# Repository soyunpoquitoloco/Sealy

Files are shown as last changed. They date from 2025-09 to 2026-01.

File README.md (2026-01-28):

# Sealy 🦭  
**Playful robotic companion for everyday productivity (posture • fatigue • phone distraction)**

Sealy is a small, seal-like desktop companion that supports focus through **low-demand, nonverbal mirroring**. Instead of notifications, scores, or “warnings,” Sealy uses **slow, peripheral, socially legible motions**:
- **Posture drift →** Sealy subtly *slumps* to mirror you  
- **Fatigue cues →** Sealy *gradually closes its eyelids*  
- **Phone distraction →** Sealy *turns away* from its “fishing hole” by rotating its base

Capture d’écran 2026-01-28 à 01 43 39

This repo contains the **software**, **hardware notes**, and **fabrication assets** used to build and run Sealy.  
(Technical and study protocol details are documented in the accompanying paper.) :contentReference[oaicite:0]{index=0}

---

## Contents
- [Project at a glance](#project-at-a-glance)
- [Prototype iterations](#prototype-iterations)
- [Repository layout](#repository-layout)
- [System overview](#system-overview)
- [Bill of materials](#bill-of-materials)
- [Fabrication & assembly](#fabrication--assembly)
- [Software setup](#software-setup)
- [How to use](#how-to-use)
- [Preliminary lab study & evaluation plan](#preliminary-lab-study--evaluation-plan)
- [Media](#media)
- [Citation](#citation)

---

## Project at a glance
**Design goal:** Reduce brief self-regulation lapses (posture drift, fatigue, phone checks) with **ambient co-regulation** cues that feel **supportive, not supervisory**. :contentReference[oaicite:1]{index=1}

**Key design constraints:**
- perceivable in peripheral vision  
- no speech, alerts, or explicit “correction”  
- slow transitions, small amplitudes  
- avoid “being watched” impressions via on-device inference and minimal logging :contentReference[oaicite:2]{index=2}

---

## Prototype iterations

There are **four physical prototypes**. 

Capture d’écran 2026-01-28 à 01 42 11

### Prototype 1 — Origami scale mock
**What it was:** Paper origami seal.

**Why:**  
- validate **desk footprint**, approximate height, and “presence” in peripheral vision  
- test early **role framing** (“pet” vs “monitor”) without committing to materials or mechanics  
- quickly iterate silhouette (roundness, head size, flipper placement) for “baby-schema” readability :contentReference[oaicite:3]{index=3}

**What we learned → what changed next:**  
Origami is great for proportions but can’t validate **mount points**, servo routing, or deformation. Next step required a rigid, printable geometry to start integrating mechanisms.

---

### Prototype 2 — 3D printed PLA body
**What it was:** Full PLA print of Sealy.

**Why:**  
- confirm **3D model correctness** (surface continuity, eye/face legibility, printability)  
- test **mechanical integration**: internal clearances, routing for eyelids/posture line, base interface  
- verify “desk object” presence and camera placement constraints

**What we learned → what changed next:**  
PLA validates geometry, but the interaction goal includes a **soft companion feel** (tactility + deformation). Rigid plastic reads more like a gadget/toy shell and limits lifelike slumping. Next step: silicone casting.

---

### Prototype 3 — Silicone cast (full silicone, rigid feel)
**What it was:** Silicone part cast in a 3D printed mold, but **the body is fully silicone (solid)** → results in *low flexibility* for expressive deformation.

**Why:**  
- explore **tactile affordances** (softness, warmth, “pet-like” handling)  
- attempt deformation-driven motions (slump/breathing) via material compliance rather than only joints

**What we learned → what changed next:**  
A **fully-solid silicone** body tends to be:
- **too stiff / too massive** to deform visibly with small servos
- harder to create predictable motion (deformation becomes “mushy” or barely noticeable)
- difficult for cable/servo integration (channels, anchors, eyelid linkage)

So the next iteration needed **softness at the surface** *without* losing a controllable internal structure.

---

### Prototype 4 — Silicone “skin” (Rebound 25) over PLA core (flexible outer layer)
**What it was:** A PLA printed model used to create a silicone skin using **Rebound 25**, keeping **only the external silicone layer** (more flexible), with an internal rigid structure for mounting.

**Why this solved Prototype 3’s limits:**
- **Soft-touch exterior** preserves pet-like tactility and “cute” embodiment
- **Rigid inner core** provides:
  - stable servo mounts and anchors (posture line, eyelid linkage)
  - consistent kinematics (repeatable slump angle, eyelid closure range)
- **Lower actuation load**: servos deform a thin skin far more effectively than a solid silicone block

This aligns with Sealy’s technical intent: expressive, low-amplitude motion that remains readable and calm. :contentReference[oaicite:4]{index=4}

---

## Repository layout

```
Companion/
├── README.md                          # This file
├── yolov8n.pt                         # YOLOv8n model weights
│
├── Programme PC/                      # PC-side programs
│   ├── detect_phone.py                # Phone detection module
│   ├── Emotions.py                    # Emotion detection (legacy)
│   ├── Posture_old.py                 # Old posture detection
│   ├── yolov8n.pt                     # Model weights (copy)
│   │
│   ├── Digital/                       # Digital prototype
│   │   ├── Animation.py               # Animation logic
│   │   ├── Detection.py               # Detection pipeline
│   │   └── main.py                    # Entry point
│   │
│   ├── Programme_general/             # Main integrated system
│   │   ├── main.py                    # Main detection loop (posture + phone)
│   │   ├── posture.py                 # Posture calibration & detection
│   │   ├── websocket_client.py        # WebSocket communication to ESP32
│   │   └── yolov8n.pt                 # Model weights
│   │
│   └── tiredness_detection/           # Fatigue detection system
│       ├── main.py                    # Entry point
│       ├── config.py                  # Configuration parameters
│       ├── fatigue_detector.py        # Core fatigue detection
│       ├── metrics.py                 # EAR, MAR metrics
│       ├── requirements.txt           # Python dependencies
│       └── README.md                  # Module documentation
```

---

## System overview

### Sensing (PC / webcam)
Sealy uses on-device computer vision to estimate:
- **Posture** via **MediaPipe Pose** (baseline calibration, then compare shoulder/spine deviation)
- **Fatigue** via **MediaPipe Face Mesh** (EAR, MAR, PERCLOS-style eye closure)
- **Phone use** via pose + **YOLOv8n** object detection :contentReference[oaicite:6]{index=6}

### State → behavior mapping (robot)
- **Posture drift →** servo-driven “slump” (mirrors direction/weight)
  
Capture d’écran 2026-01-28 à 01 46 07

- **Fatigue →** eyelids gradually close; tempo reduces
  
- **Phone distraction →** base rotates away from the fishing hole :contentReference[oaicite:7]{index=7}
  
Capture d’écran 2026-01-28 à 01 45 13

### Comms
PC runs a processing loop and transmits state to the device via a **WebSocket**-style connection for synchronized responses. :contentReference[oaicite:8]{index=8}

---

## Bill of materials

### Electronics
- Webcam (PC-facing; can be laptop webcam)
- **1× stepper motor** + driver (for rotating base)
- **2× servo motors**
  - posture/breathing (pull line)
  - eyelids (wire linkage)
- Controller: **ESP32 Devkit** 
- Power supply 5V
- Wires, connectors

Capture d’écran 2026-01-28 à 01 49 39

### Mechanical
- Rotating platform + gear assembly (for ice-floe metaphor)
- Fishing-hole top reference (visual orientation cue)
- Transparent fishing line (posture actuation, eyelids)
  
Capture d’écran 2026-01-28 à 01 50 16

### Fabrication
- PLA filament (body core, base components, molds as needed)
- Silicone: **Rebound 25** (skin)
- Mold release spray + mixing supplies (cups, stir sticks, gloves)

---

## Fabrication & assembly

### A) Build the body (Prototype 4 recommended)
1. **3D print** the Sealy body core in PLA and the other components.
2. Prepare the **mold workflow** for a thin silicone skin:
   - use the PLA model as the master
   - apply mold release
3. Mix and brush/apply **Rebound 25** in layers to achieve a uniform skin thickness.
4. Demold the skin.

Capture d’écran 2026-01-28 à 01 54 27

**Why this works:** thin silicone skin gives visible deformation under low torque, while the PLA core allowed to keep motion repeatable.

### B) Assemble the base (rotation)
1. Mount the stepper motor, and platform.
2. Ensure the base can rotate smoothly through the intended angle range (e.g., ~30° for “turn away”). :contentReference[oaicite:10]{index=10}
3. Align Sealy with the platform to make it face the fishing hole.

### C) Add actuators
- **Posture servo:** attach fishing line to a secure anchor on Sealy’s back; route line to servo horn so it can “pull” a controlled slump.
- **Eyelid servo:** connect eyelids via thin wires so the servo can close them gradually (aim ~50% closure for readability). :contentReference[oaicite:11]{index=11}

### D) Wire + power
- Keep stepper power isolated/adequate; servos can brown-out controllers if underpowered.
- Strain-relief all moving wires (rotation + servo motion).

---

## Software setup

### 1) PC-side (vision + state server)
**Expected dependencies:**
- Python 3.9+
- `opencv-python`
- `mediapipe`
- `ultralytics` (YOLOv8)
- `numpy`
- `websockets` (or equivalent)

**Installation:**
```bash
pip install opencv-python mediapipe ultralytics numpy websockets
```

**Directory options:**

- **`Programme_general/`** (recommended): integrated posture + phone detection with WebSocket communication
  ```bash
  cd "Programme PC/Programme_general"
  python main.py
  ```

- **`tiredness_detection/`**: standalone fatigue detection system
  ```bash
  cd "Programme PC/tiredness_detection"
  pip install -r requirements.txt
  python main.py
  ```
  
  Optional arguments:
  - `--camera-index N` — select camera device (default: 0)
  - `--no-calibration` — skip calibration, use default thresholds
  - `--ear-threshold 0.20` — customize eye aspect ratio threshold
  - `--log-level DEBUG` — set logging verbosity

**Configuration:**
- On first run, the system will **calibrate** your neutral posture (stay upright for ~5 seconds)
- Adjust detection thresholds in `config.py` (fatigue module) or directly in `main.py` scripts
- Ensure YOLOv8n weights (`yolov8n.pt`) are present in the working directory

---

### 2) Device-side (ESP32)

**Expected dependencies:**
- Arduino IDE or PlatformIO for ESP32 development
- ESP32 board support package
- Required libraries:
  - `ESP32Servo` (for servo control)
  - `AccelStepper` or `Stepper` (for stepper motor)
  - `WebSocketsServer` or `AsyncWebSocket` (for WebSocket communication)

**Setup:**
1. Flash firmware to ESP32:
   - Open the ESP32 firmware project in Arduino IDE or PlatformIO
   - Configure WiFi credentials and WebSocket port
   - Upload to ESP32 board

2. Configure PC connection:
   - Update WebSocket endpoint in `Programme_general/websocket_client.py` with your ESP32's IP address
   - Ensure both PC and ESP32 are on the same network

**Hardware wiring:**
- Connect servos to ESP32 GPIO pins (servo1 for slumping : 27, servo2 for eyelids : )
- Connect stepper motor driver to appropriate pins (Pin1 : 13, Pin2 : 26, Pin3 : 25, Pin4 : 33) 
- Use external power supply for motors 5V
---

## How to use

### First-time setup
1. **Build the physical prototype** (see [Fabrication & assembly](#fabrication--assembly))
2. **Install software** on both PC and ESP32 (see [Software setup](#software-setup))
3. **Connect hardware**: plug in webcam, power on Sealy, establish PC ↔ ESP32 communication
4. **Calibrate**: run the PC program and hold good posture during calibration countdown

### Daily use workflow
1. **Start the ESP32** (ensure it's powered on and connected to WiFi)
2. **Start PC detection**:
   ```bash
   cd "Programme PC/Programme_general"
   python main.py
   ```
3. **Position yourself** in front of the webcam, with Sealy visible in your peripheral vision
4. **Work naturally** — Sealy will respond to:
   - **Posture drift**: if you slump or lean, Sealy mirrors the motion

Capture d’écran 2026-01-28 à 02 03 16

   - **Fatigue signs**: if your eyes close repeatedly, Sealy's eyelids droop

Capture d’écran 2026-01-28 à 02 03 48

   - **Phone checks**: if you pick up your phone, Sealy rotates away from the fishing hole

Capture d’écran 2026-01-28 à 02 04 12

### Interpreting Sealy's cues
- **Slump motion** → gentle reminder to adjust posture (not a "correction," just mirroring)
- **Eyelid closure** → fatigue detected; consider a break or eye rest
- **Base rotation** → phone distraction noticed; Sealy "looks away" to create ambient awareness

### Stopping / pausing
- Press `q` or `Ctrl+C` in the terminal to stop detection
- Device motors return to neutral positions
- No data is logged by default (privacy by design)

---

## Preliminary lab study & evaluation plan

### Study goals
Evaluate whether **nonverbal ambient cues** from Sealy can:
1. Reduce frequency/duration of posture lapses, fatigue incidents, and phone checks
2. Feel supportive rather than supervisory (subjective perception)
3. Maintain effectiveness over multi-day usage (habituation assessment)

### Study design (future work)
- **Participants**: 4 workers (students/office workers)
- **Protocol**: 
  - Baseline session (no Sealy): 15-20 min focused task
  - Sealy session: 15-20 min focused task with Sealy active
  - Counterbalanced order (half start with Sealy, half without)
- **Measures**:
  - **Quantitative**: posture deviation frequency, phone pickup count, eye closure duration (via logs)
  - **Qualitative**: post-session interview (NASA-TLX workload, perceived support vs. surveillance)

### Next steps
- Test on 4 participant
- Long-term deployment (1 week) to assess habituation
- Compare Sealy to explicit notifications (e.g., popup alerts) for perceived intrusiveness

---

## Media

### Photos

Capture d’écran 2026-01-28 à 01 56 21

Capture d’écran 2026-01-28 à 01 56 45

### Demo videos

https://github.com/user-attachments/assets/3ee4d5ab-db28-43dc-951a-25afe59001c0

### Design process

Capture_d_écran_2026-01-22_à_23 58 56-removebg-preview

Capture_d_écran_2026-01-22_à_23 59 40-removebg-preview

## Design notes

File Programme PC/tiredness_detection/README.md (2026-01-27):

# Fatigue Detection System

Système de détection de fatigue en temps réel utilisant la webcam. Détecte les signes de fatigue comme les yeux fermés, les bâillements et les clignements prolongés.

## Fonctionnalités

- **Détection en temps réel** : Analyse vidéo à 15-30 FPS sur CPU
- **Détection des yeux fermés** : EAR (Eye Aspect Ratio) + PERCLOS
- **Détection des bâillements** : MAR (Mouth Aspect Ratio)
- **Clignements longs** : Détection des micro-siestes
- **Score de fatigue** : Calcul pondéré avec lissage
- **Alertes intelligentes** : Hystérésis + cooldown
- **Calibration automatique** : Adaptation à l'utilisateur
- **Privacy-first** : Tout en local, pas d'enregistrement

## Prérequis

- Python 3.10 ou supérieur
- Webcam fonctionnelle
- macOS, Linux ou Windows

## Installation

### 1. Cloner ou créer le projet

```bash
cd /Users/emilie/tiredness_detection
```

### 2. Créer un environnement virtuel (recommandé)

```bash
python3 -m venv venv
source venv/bin/activate  # Sur macOS/Linux
# ou
venv\Scripts\activate  # Sur Windows
```

### 3. Installer les dépendances

```bash
pip install -r requirements.txt
```

## Utilisation

### Lancement basique

```bash
python main.py
```

### Options disponibles

```bash
# Utiliser une autre caméra
python main.py --camera-index 1

# Désactiver la calibration
python main.py --no-calibration

# Ajuster les seuils
python main.py --ear-threshold 0.18 --mar-threshold 0.65

# Mode debug
python main.py --log-level DEBUG
```

### Commandes pendant l'exécution

- **`q`** : Quitter l'application
- **`r`** : Réinitialiser l'état de fatigue

## Métriques affichées

| Métrique | Description | Valeurs normales |
|---|---|---|
| **EAR** | Eye Aspect Ratio | 0.25-0.35 (ouvert), <0.20 (fermé) |
| **MAR** | Mouth Aspect Ratio | <0.5 (fermé), >0.6 (bâillement) |
| **PERCLOS** | % temps yeux fermés | <15% (OK), >15% (fatigue) |
| **Yawns/min** | Bâillements par minute | <3 (OK), >3 (fatigue) |
| **Score** | Score de fatigue global | <0.5 (OK), >0.5 (fatigue) |

## Configuration

Tous les paramètres sont ajustables dans `config.py` :

### Seuils principaux

```python
# Yeux
EAR_THRESHOLD = 0.21              # Seuil EAR pour yeux fermés
EYE_CLOSED_MIN_FRAMES = 2         # Frames min pour considérer fermé
PERCLOS_THRESHOLD = 0.15          # 15% du temps

# Bâillements
MAR_THRESHOLD = 0.6               # Seuil MAR pour bâillement
YAWN_MIN_FRAMES = 10              # Frames min pour bâillement

# Score de fatigue
FATIGUE_SCORE_THRESHOLD = 0.5     # Seuil d'alerte
FATIGUE_TRIGGER_SECONDS = 3.0     # Durée avant alerte
FATIGUE_COOLDOWN_SECONDS = 10.0   # Cooldown entre alertes
```

### Poids du score de fatigue

```python
WEIGHT_PERCLOS = 0.4       # 40% du score
WEIGHT_YAWNS = 0.3         # 30% du score
WEIGHT_LONG_BLINKS = 0.3   # 30% du score
```

### Calibration

```python
CALIBRATION_ENABLED = True
CALIBRATION_DURATION_SECONDS = 5.0
CLOSED_RATIO = 0.70  # Seuil = 70% de l'EAR moyen ouvert
```

## Architecture

```
tiredness_detection/
├── main.py                 # Point d'entrée, boucle principale
├── fatigue_detector.py     # Classe FatigueDetector
├── metrics.py              # Calculs EAR, MAR, PERCLOS
├── config.py               # Configuration et seuils
├── requirements.txt        # Dépendances
└── README.md              # Documentation
```

### Flux de traitement

```
Webcam → MediaPipe FaceMesh → Landmarks
                                  ↓
                    ┌─────────────┴─────────────┐
                    ↓                           ↓
                 Yeux (EAR)                 Bouche (MAR)
                    ↓                           ↓
              ┌─────┴────┐                 Bâillements
              ↓          ↓                      ↓
         PERCLOS    Long Blinks           Yawns/min
              ↓          ↓                      ↓
              └──────────┴──────────────────────┘
                             ↓
                      Fatigue Score
                             ↓
                      ┌──────┴──────┐
                      ↓             ↓
                  OK/WARNING    FATIGUE ALERT
```

## Ajustements et optimisation

### Si trop d'alertes

1. Augmenter `FATIGUE_SCORE_THRESHOLD` (ex: 0.6 ou 0.7)
2. Augmenter `FATIGUE_TRIGGER_SECONDS` (ex: 5.0)
3. Réduire les poids `WEIGHT_*`
4. Augmenter `EAR_THRESHOLD` (ex: 0.19)

### Si pas assez d'alertes

1. Diminuer `FATIGUE_SCORE_THRESHOLD` (ex: 0.4)
2. Diminuer `EAR_THRESHOLD` (ex: 0.23)
3. Diminuer `MAR_THRESHOLD` (ex: 0.55)
4. Augmenter les poids `WEIGHT_*`

### Optimisation performance

- Réduire `FRAME_WIDTH` et `FRAME_HEIGHT` dans config.py
- Désactiver `DRAW_LANDMARKS` si non nécessaire
- Réduire `PERCLOS_WINDOW_SECONDS` pour moins d'historique

## Résolution de problèmes

### Caméra ne s'ouvre pas

```bash
# Tester les indices disponibles
python -c "import cv2; print([i for i in range(5) if cv2.VideoCapture(i).isOpened()])"

# Utiliser l'indice trouvé
python main.py --camera-index <indice>
```

### FPS faible (<15)

- Fermer les autres applications utilisant la caméra
- Réduire la résolution dans config.py
- Vérifier les processus CPU

### Pas de détection de visage

- Assurez-vous d'être bien éclairé
- Positionnez-vous face à la caméra
- Ajustez `MIN_DETECTION_CONFIDENCE` dans config.py

### Alertes erratiques

- Lancez avec calibration activée
- Ajustez `SCORE_SMOOTHING_ALPHA` (0.2-0.4)
- Augmentez `FATIGUE_TRIGGER_SECONDS`

## Landmarks MediaPipe

Le système utilise MediaPipe FaceMesh (468 landmarks) :

- **Yeux gauche** : indices 33, 160, 158, 133, 153, 144, etc.
- **Yeux droit** : indices 362, 385, 387, 263, 373, 380, etc.
- **Bouche** : indices 61, 291, 13, 14, 12, 15, 11, 16, etc.

Voir [MediaPipe Face Mesh](https://github.com/google/mediapipe/blob/master/docs/solutions/face_mesh.md) pour les détails.

## Améliorations futures (TODO)

- [ ] **Head pose estimation** : Détection de la tête qui tombe
- [ ] **Export des données** : Logging des métriques (CSV)
- [ ] **Alertes sonores** : Notification audio configurable
- [ ] **Dashboard** : Graphiques temps réel
- [ ] **Multi-visages** : Support de plusieurs personnes
- [ ] **GPU acceleration** : Support CUDA/Metal
- [ ] **Configuration UI** : Interface pour ajuster les seuils

## Licence

Projet éducatif - Libre d'utilisation et de modification.

## Crédits

- **MediaPipe** : Google (détection de visage et landmarks)
- **OpenCV** : Traitement d'image et vidéo
- **EAR/MAR** : Métriques basées sur la recherche académique

## Support

Pour toute question ou problème, ouvrez une issue ou consultez les logs avec `--log-level DEBUG`.

---

**Note** : Ce système est conçu pour la détection de fatigue en temps réel mais ne remplace pas une évaluation médicale professionnelle. Utilisez-le de manière responsable.

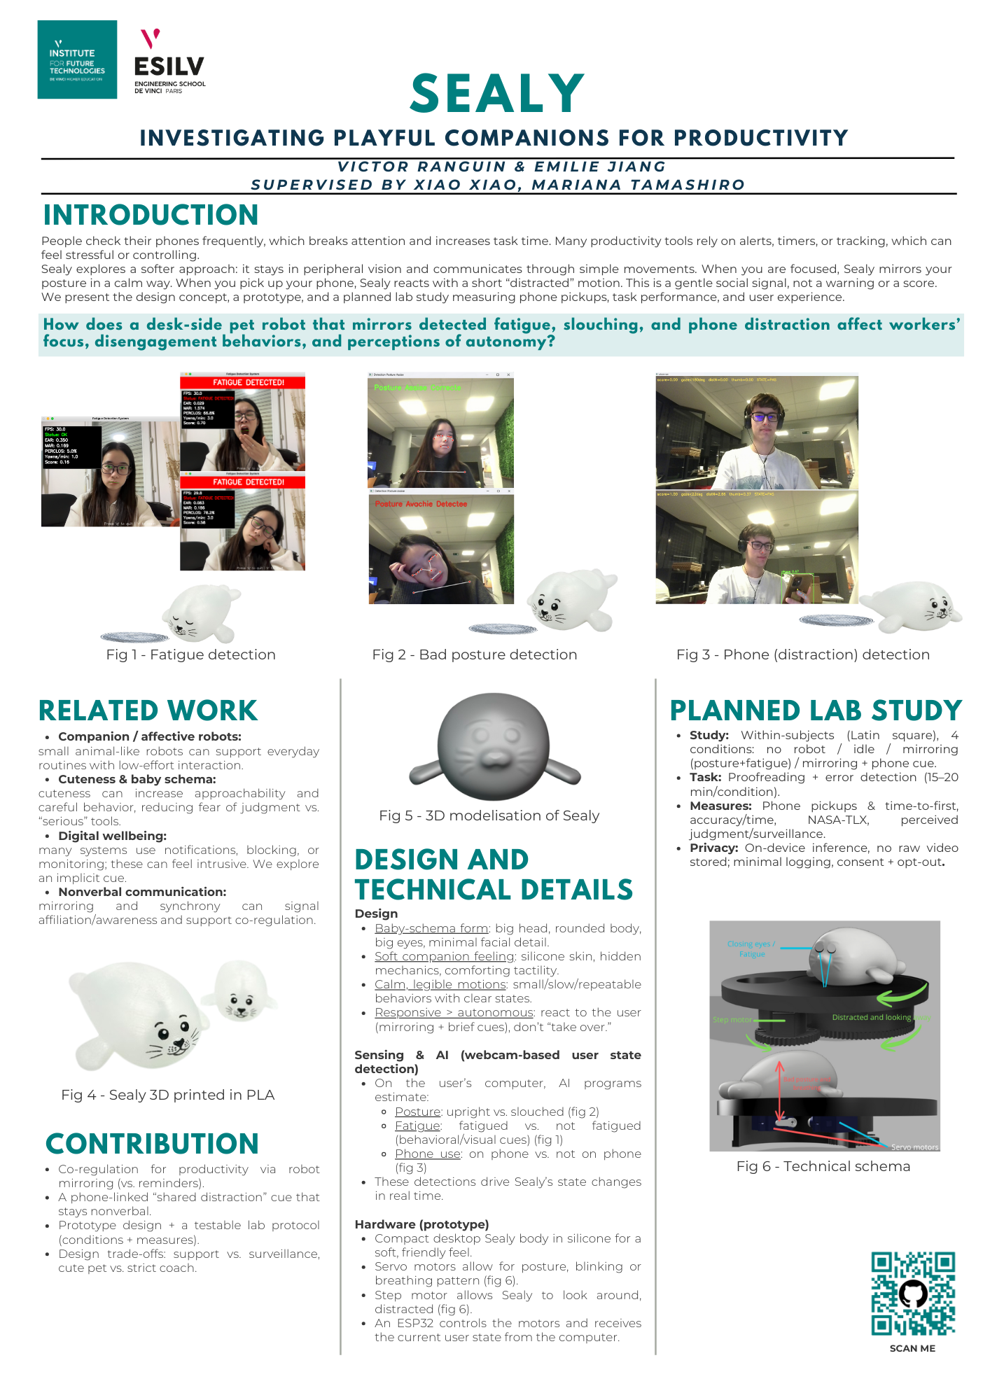
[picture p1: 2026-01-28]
Documentation/Sealy-Poster.png

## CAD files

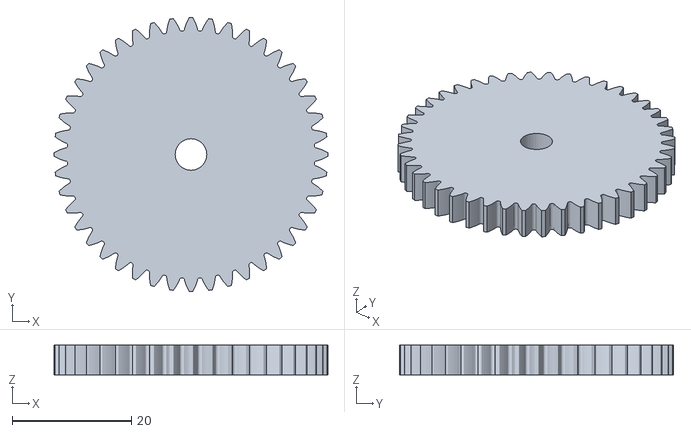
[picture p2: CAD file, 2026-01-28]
3D_files/Axial_gear.stl
46.0 x 46.0 x 5.00

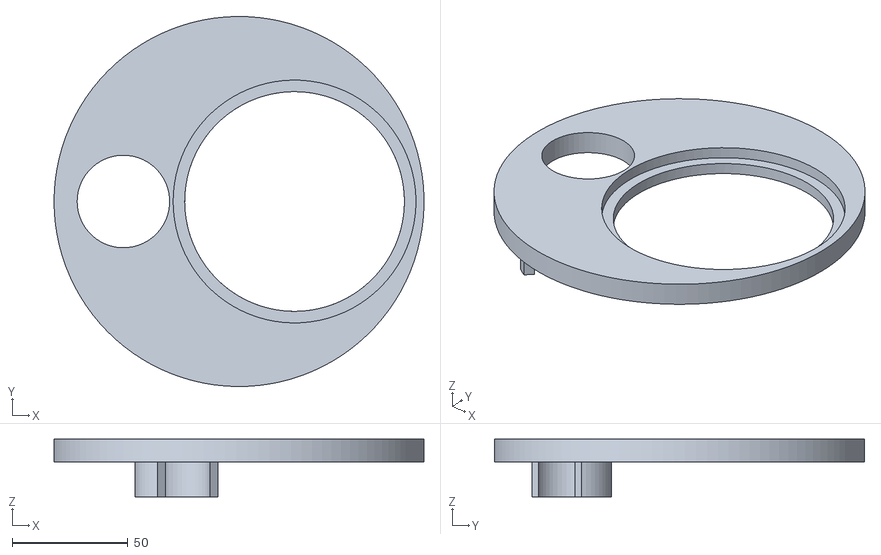
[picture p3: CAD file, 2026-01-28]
3D_files/Socle_sealy.stl
160.0 x 160.0 x 25.0

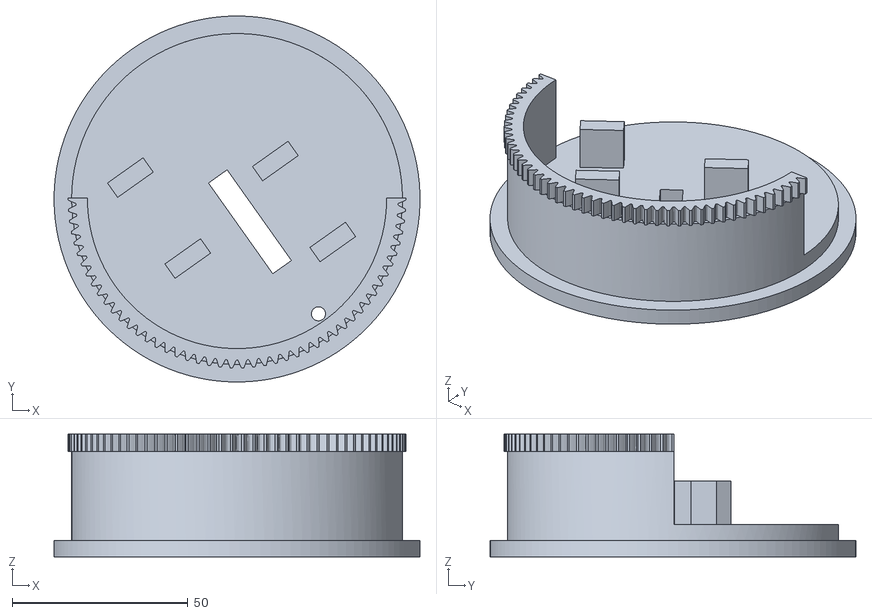
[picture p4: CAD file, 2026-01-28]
3D_files/Plate_sealy.stl
104.0 x 104.0 x 34.9

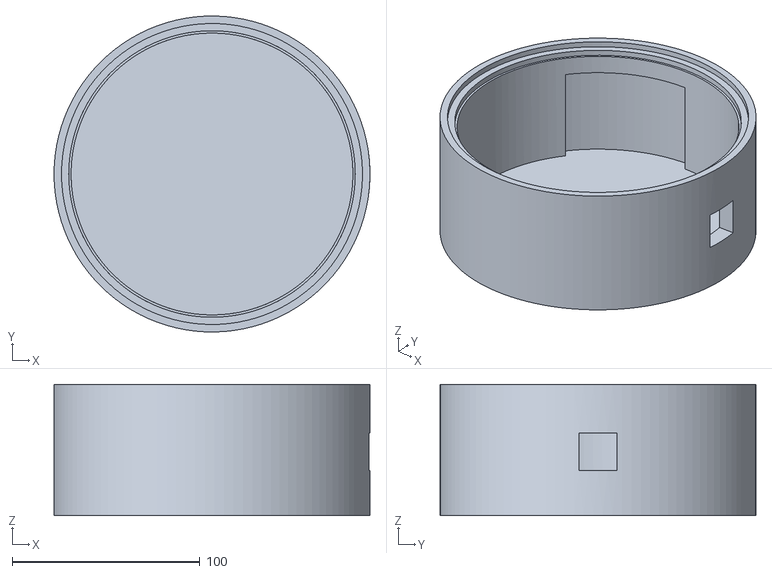
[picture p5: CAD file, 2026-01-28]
3D_files/Support_socle.stl
168.4 x 168.4 x 70.0

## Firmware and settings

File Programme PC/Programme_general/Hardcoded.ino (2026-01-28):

#include <ESP32Servo.h>
#include <WiFi.h>
#include <WebSocketsServer.h>

// Déclaration du servomoteur
Servo servo1;

const char* ssid = "";
const char* password = "";

WebSocketsServer webSocket = WebSocketsServer(80);
String message;

void onWebSocketEvent(uint8_t num, WStype_t type, uint8_t * payload, size_t length) {
    switch (type) {
        case WStype_CONNECTED: {
            Serial.printf("Client %u connecté\n", num);
            webSocket.sendTXT(num, "w00t");
            break;
        }
        case WStype_DISCONNECTED: {
            Serial.printf("Client %u déconnecté\n", num);
            break;
        }
        case WStype_TEXT: {
            message = (char *)payload;
            Serial.println(message);
            break;
        }
        default: {
            break;
        }
    }
}

// Broches du moteur pas-à-pas
#define STEPPER_PIN_1 13
#define STEPPER_PIN_2 26
#define STEPPER_PIN_3 25
#define STEPPER_PIN_4 33

int step_number = 0;

void setup() {
    // Initialisation du servomoteur
    servo1.attach(27);
    delay(100);

    // Initialisation des broches du moteur pas-à-pas
    pinMode(STEPPER_PIN_1, OUTPUT);
    pinMode(STEPPER_PIN_2, OUTPUT);
    pinMode(STEPPER_PIN_3, OUTPUT);
    pinMode(STEPPER_PIN_4, OUTPUT);

    // Initialisation de la communication série
    Serial.begin(9600);
    Serial.println("Prêt !");
    WiFi.begin(ssid, password);
    while (WiFi.status() != WL_CONNECTED) {
        delay(1000);
        Serial.println("Connecting to WiFi...");
    }
    Serial.println("Connected to WiFi");
    Serial.println(WiFi.localIP());
    Serial.println("Starting WebSocket server...");
    webSocket.begin();
    webSocket.onEvent(onWebSocketEvent);
    Serial.println("Server ready");
}

bool keep_posture = false;
bool isRotating = false;
bool keep_distracted = false;

void loop() {
    webSocket.loop();

    // Vérifie les messages WebSocket (pas besoin de Serial.available())
    if ((message == "posture not_distracted" && keep_posture == true) ||(message == "posture distracted" && keep_posture == true)) {
        Serial.println("Activation du servomoteur...");
        // Tourne progressivement de 180° à 90°
        for (int angle = 180; angle >= 90; angle -= 1) {
            servo1.write(angle);
            delay(15);
        }
        //servo1.write(90);
        keep_posture = false;
    } 
    else if (message == "not_posture not_distracted" || message == "not_posture distracted") {
          servo1.write(180);
          keep_posture = true;
    }
    if ((message == "posture distracted" || message == "not_posture distracted") && (!isRotating && keep_distracted == false)) {
        Serial.println("Activation du moteur pas-à-pas (90° aller-retour)...");
        isRotating = true;
        rotate90();
        isRotating = false;
        keep_distracted = true;
    }
    else if ((message == "posture not_distracted" || message == "not_posture not_distracted") && (!isRotating && keep_distracted == true)) {
      //Serial.println("Activation du moteur pas-à-pas (90° aller-retour)...");
        isRotating = true;
        rotateBack();
        isRotating = false;
        keep_distracted = false;
    }
}

void rotate90() {
    const int steps_per_revolution = 200*8;
    const int steps_90 = steps_per_revolution / 2;

    for (int i = 0; i < steps_90; i++) {
        OneStep(false);
        delay(2);
    }
}

void rotateBack() {
  const int steps_per_revolution = 200*8;
  const int steps_90 = steps_per_revolution / 2;

  for (int i = 0; i < steps_90; i++) {
        OneStep(true);
        delay(2);
    }
}
void OneStep(bool dir) {
    if (dir) {
        switch (step_number) {
            case 0:
                digitalWrite(STEPPER_PIN_1, HIGH);
                digitalWrite(STEPPER_PIN_2, LOW);
                digitalWrite(STEPPER_PIN_3, LOW);
                digitalWrite(STEPPER_PIN_4, LOW);
                break;
            case 1:
                digitalWrite(STEPPER_PIN_1, LOW);
                digitalWrite(STEPPER_PIN_2, HIGH);
                digitalWrite(STEPPER_PIN_3, LOW);
                digitalWrite(STEPPER_PIN_4, LOW);
                break;
            case 2:
                digitalWrite(STEPPER_PIN_1, LOW);
                digitalWrite(STEPPER_PIN_2, LOW);
                digitalWrite(STEPPER_PIN_3, HIGH);
                digitalWrite(STEPPER_PIN_4, LOW);
                break;
            case 3:
                digitalWrite(STEPPER_PIN_1, LOW);
                digitalWrite(STEPPER_PIN_2, LOW);
                digitalWrite(STEPPER_PIN_3, LOW);
                digitalWrite(STEPPER_PIN_4, HIGH);
                break;
        }
    } else {
        switch (step_number) {
            case 0:
                digitalWrite(STEPPER_PIN_1, LOW);
                digitalWrite(STEPPER_PIN_2, LOW);
                digitalWrite(STEPPER_PIN_3, LOW);
                digitalWrite(STEPPER_PIN_4, HIGH);
                break;
            case 1:
                digitalWrite(STEPPER_PIN_1, LOW);
                digitalWrite(STEPPER_PIN_2, LOW);
                digitalWrite(STEPPER_PIN_3, HIGH);
                digitalWrite(STEPPER_PIN_4, LOW);
                break;
            case 2:
                digitalWrite(STEPPER_PIN_1, LOW);
                digitalWrite(STEPPER_PIN_2, HIGH);
                digitalWrite(STEPPER_PIN_3, LOW);
                digitalWrite(STEPPER_PIN_4, LOW);
                break;
            case 3:
                digitalWrite(STEPPER_PIN_1, HIGH);
                digitalWrite(STEPPER_PIN_2, LOW);
                digitalWrite(STEPPER_PIN_3, LOW);
                digitalWrite(STEPPER_PIN_4, LOW);
                break;
        }
    }
    step_number++;
    if (step_number > 3) {
        step_number = 0;
    }
}

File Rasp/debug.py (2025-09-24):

import cv2
import time
from picamera2 import Picamera2
from deepface import DeepFace

# Initialisation de la caméra avec Picamera2
try:
    picam2 = Picamera2()
    config = picam2.create_preview_configuration(main={"size": (320, 240)})
    picam2.configure(config)
    picam2.start()
    print("Caméra initialisée avec succès.")
except Exception as e:
    print(f"Erreur d'initialisation de la caméra : {e}")
    exit(1)

# Chargeur de classificateur pour détection de visages
face_cascade = cv2.CascadeClassifier(cv2.data.haarcascades + 'haarcascade_frontalface_default.xml')
if face_cascade.empty():
    print("Erreur : Impossible de charger le classificateur de visages.")
    exit(1)

print("Démarrage de la capture... Appuyez sur Ctrl+C pour arrêter.")
iteration = 0

try:
    while True:
        iteration += 1
        print(f"Iteration {iteration} : Capture en cours...")
        
        # Capture d'une frame
        image = picam2.capture_array()
        print(f"  - Image capturée, taille : {image.shape}, moyenne des pixels : {image.mean():.1f} (doit être >0 si éclairé)")
        
        if image.mean() < 1:  # Si image noire/vide
            print("  - Attention : Image noire ou vide (problème caméra/lumière ?)")
        
        # Détection de visages avec OpenCV
        gray = cv2.cvtColor(image, cv2.COLOR_BGR2GRAY)
        faces = face_cascade.detectMultiScale(gray, scaleFactor=1.1, minNeighbors=5, minSize=(30, 30))
        print(f"  - Nombre de visages détectés : {len(faces)}")
        
        if len(faces) > 0:
            print("  - Visage(s) trouvé(s) ! Analyse de l'émotion...")
            (x, y, w, h) = faces[0]  # Première face
            face_roi = image[y:y+h, x:x+w]
            
            try:
                result = DeepFace.analyze(face_roi, actions=['emotion'], enforce_detection=False, detector_backend='opencv')
                dominant_emotion = result[0]['dominant_emotion']
                print(f"  - Émotion dominante : {dominant_emotion}")
                
                # Probabilités
                emotions = result[0]['emotion']
                for emotion, score in emotions.items():
                    if score > 30:  # Seuil abaissé pour plus de détails
                        print(f"    - {emotion}: {score:.1f}%")
                        
            except Exception as e:
                print(f"  - Erreur d'analyse DeepFace : {e}")
        else:
            print("  - Aucun visage détecté. Assurez-vous d'être face à la caméra.")
        
        if iteration % 5 == 0:  # Print périodique pour confirmer que la boucle tourne
            print(f"--- Boucle active (itération {iteration}) ---")
        
        time.sleep(1)  # Pause courte pour debug ; augmentez à 2-3s pour production

except KeyboardInterrupt:
    print("\nArrêt du programme.")
finally:
    picam2.stop()
    print("Caméra arrêtée.")

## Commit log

2025-11-22 add the Digital prototype codes
2026-01-27 Add of tiredness detection
2026-01-27 add tiredness detection
2026-01-28 Update README with additional prototype details and images
2026-01-28 Simplify prototype iterations section in README
    Removed reasoning chain details for prototype iterations.
2026-01-28 add the 3D files for printing, the right typo for the documentation part and the arduino code for the esp32, and a demo
    [Axial_gear.stl, Plate_sealy.stl, Socle_sealy.stl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]
